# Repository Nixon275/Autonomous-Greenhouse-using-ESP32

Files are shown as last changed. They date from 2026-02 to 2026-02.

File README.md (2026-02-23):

# 🌱 Autonomous Greenhouse — ESP32 IoT System

> **Real-time monitoring and automatic regulation of microclimatic conditions in a plant growth enclosure, powered by ESP32 and the ESP RainMaker cloud platform.**

---

## What is this?

This project is a fully functional smart greenhouse system built around the **ESP32 microcontroller (ESP32-DevKitC V4)** and Espressif's **ESP-IDF** framework. It monitors and automatically controls the key environmental parameters that determine whether your plants thrive — all accessible from your phone, from anywhere in the world.

The system continuously reads five environmental parameters, sends the data to the cloud, and fires up actuators autonomously to keep conditions optimal — no human intervention required.

---

## 📸 Demo — Physical Build

<p align="center">
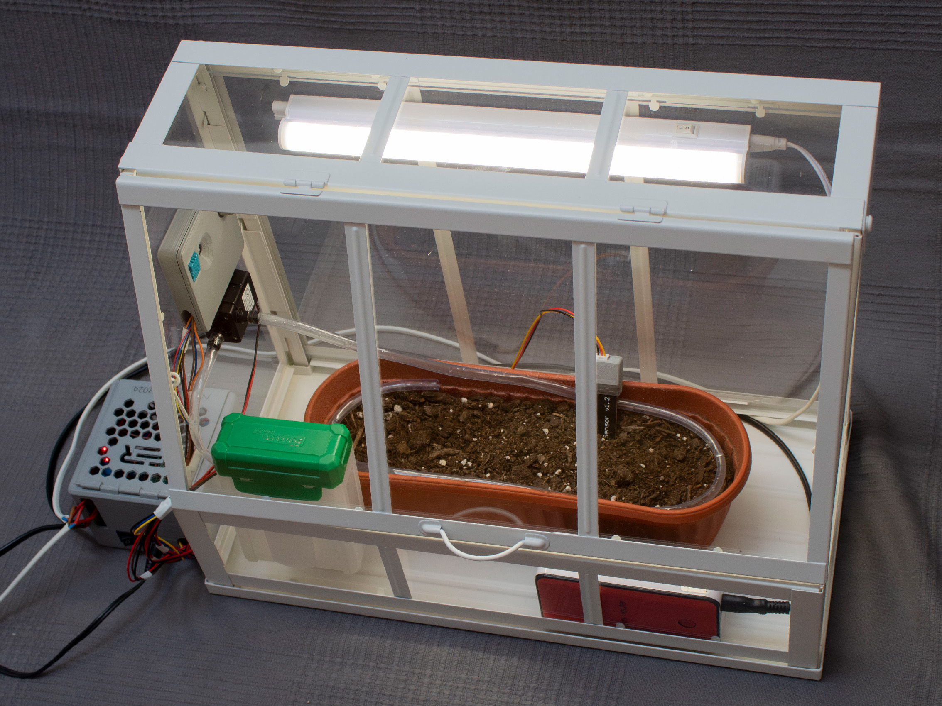
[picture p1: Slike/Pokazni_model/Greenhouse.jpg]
  
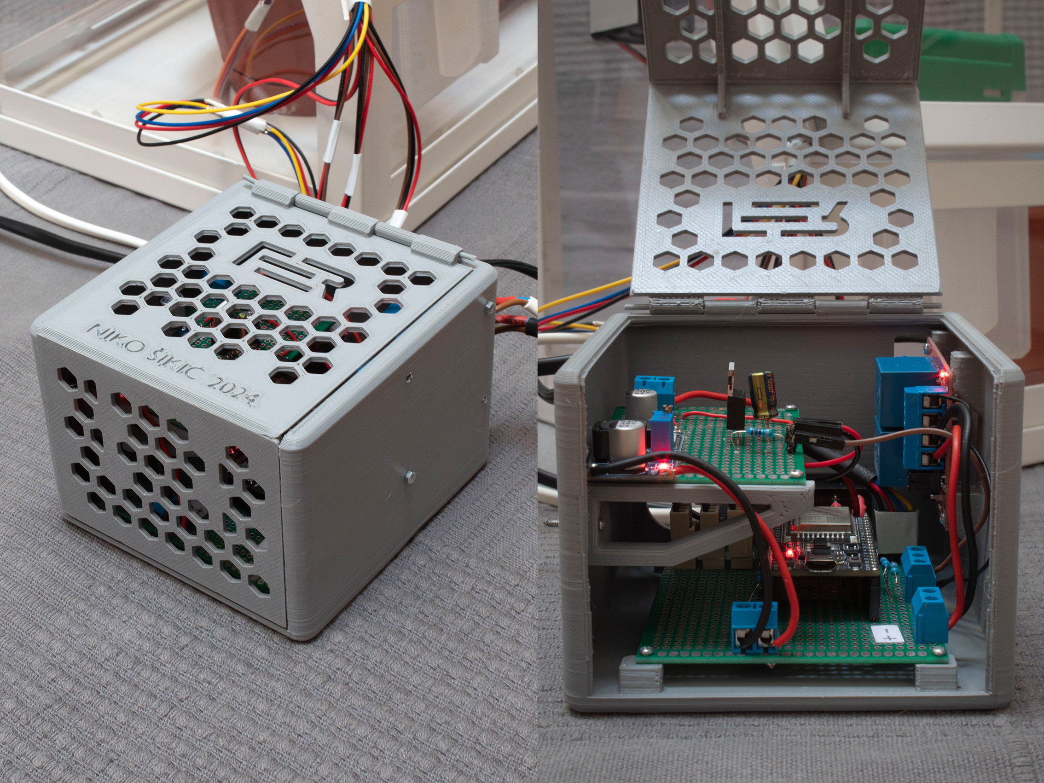
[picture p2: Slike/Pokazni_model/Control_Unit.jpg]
  
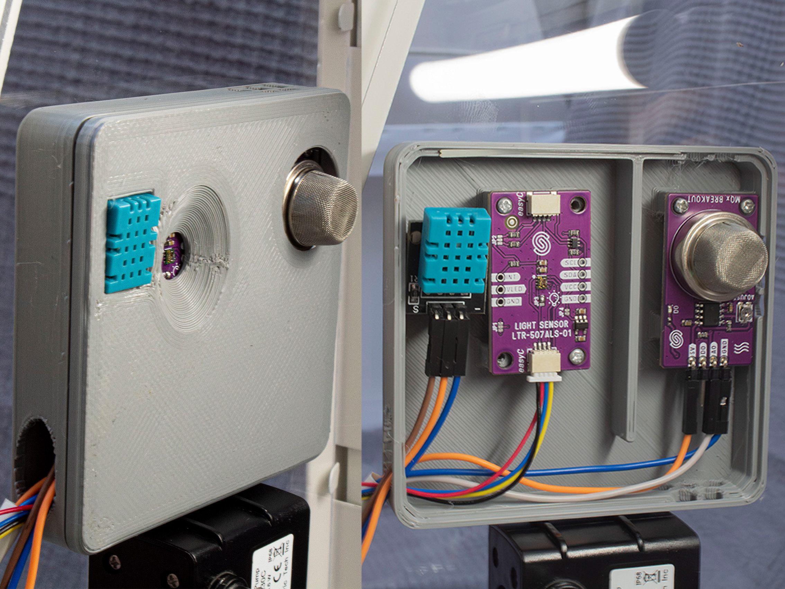
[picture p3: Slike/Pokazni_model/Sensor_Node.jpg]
  
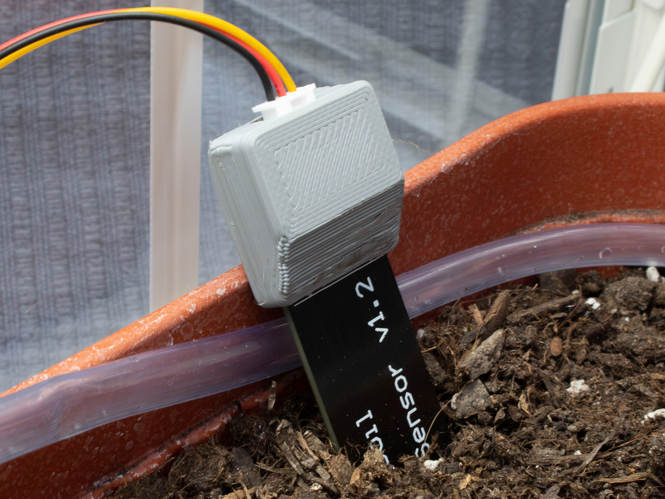
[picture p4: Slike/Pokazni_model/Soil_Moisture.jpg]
  
</p>

---

## 📐 System Architecture

<p align="center">
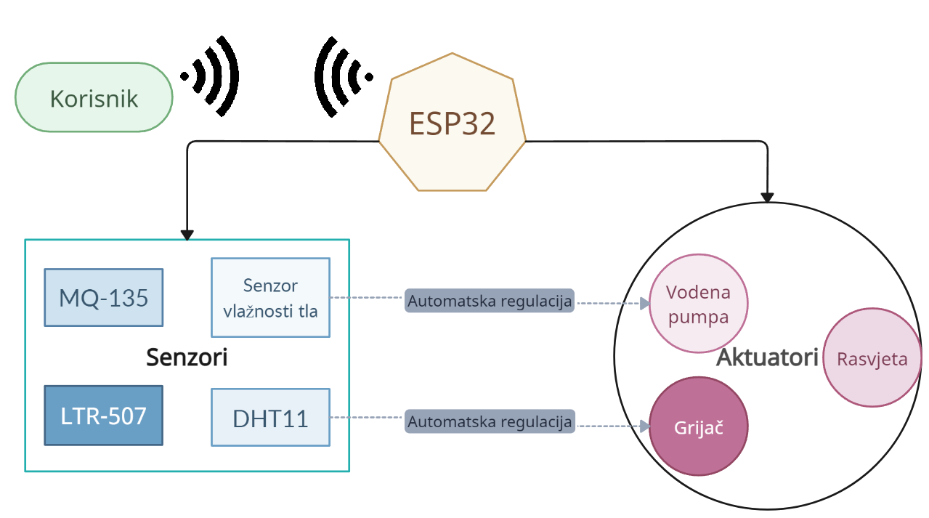
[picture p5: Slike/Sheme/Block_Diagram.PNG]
  
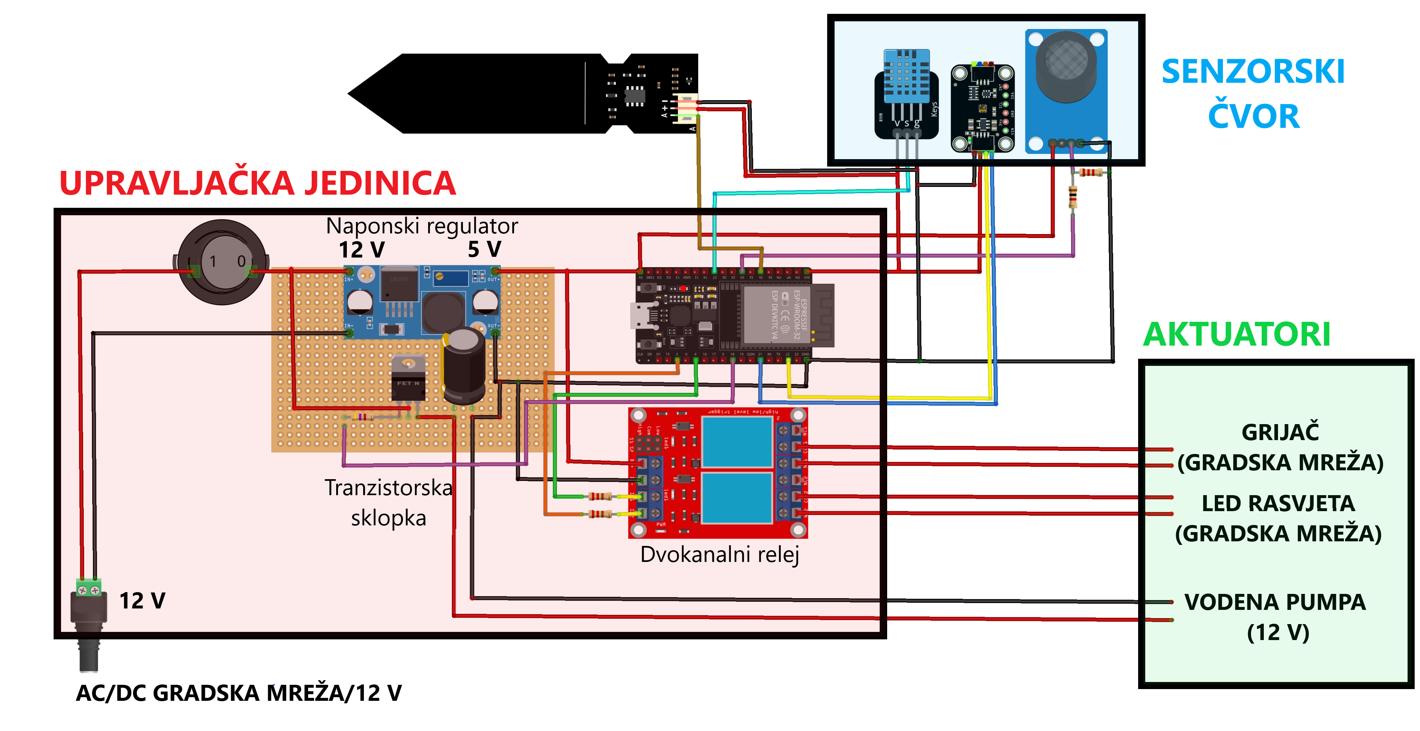
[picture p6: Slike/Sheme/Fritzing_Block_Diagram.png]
  
</p>

---

## ⚙️ What it monitors & controls

| Parameter | Sensor | Actuator |
|---|---|---|
| 🌡️ Air temperature | DHT11 | Electric heater |
| 💧 Air humidity | DHT11 | — |
| 🌿 CO₂ concentration | MQ-135 | — |
| 🪴 Soil moisture | Capacitive sensor v1.2 | Water pump |
| 💡 Light intensity | LTR-507-ALS-01 | LED grow light |

---

## 📱 Remote Access via ESP RainMaker

The system connects over **Wi-Fi** and streams sensor data to the **ESP RainMaker cloud**. Through the mobile app you can:

- View live and historical sensor readings (plotted over time)
- Set target temperature and soil moisture thresholds
- Manually toggle the LED grow light
- Schedule actuators based on time of day
- Get notified of parameter changes

---

## 🎬 Demo Video

> 📁 **[Watch the demo here →](https://drive.google.com/file/d/1RN_uDvcak08naD7JZQC7uZy4IQwOXqrC/view?usp=sharing)**

---

## 📄 Full Documentation

The complete written thesis (hardware design, sensor calibration, firmware architecture, and test results) is available in the repository:

📘 **[`Tekst/Sikic_Niko_Zavrsni_projekt.pdf`](Tekst/Sikic_Niko_Zavrsni_projekt.pdf)**

---

## 🛠️ Tech Stack

- **Microcontroller:** ESP32-DevKitC V4 (ESP32-WROOM-32E)
- **Framework:** ESP-IDF (C)
- **Cloud platform:** ESP RainMaker (MQTT over TLS)
- **Protocols:** 1-Wire (DHT11), I²C (LTR-507), ADC (MQ-135, soil sensor)
- **Control logic:** On/Off (bang-bang) regulation with FreeRTOS timers
- **Enclosures:** Custom-designed in Blender, 3D printed

---

## 📁 Firmware Structure

```
main/
├── app_main.c
├── app_driver.c
├── DHT11.c / .h
├── LTR-507.c / .h
├── MQ-135.c / .h
├── soil_moisture.c / .h
└── device.c / .h
```

---

*Bachelor's thesis — Faculty of Electrical Engineering and Computing (FER), University of Zagreb, 2024.*  
*Author: Niko Šikić | Mentor: Prof. dr. sc. Hrvoje Džapo*

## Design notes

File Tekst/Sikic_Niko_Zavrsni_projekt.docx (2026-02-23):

SVEUČILIŠTE U ZAGREBU

FAKULTET ELEKTROTEHNIKE I RAČUNARSTVA

Sustav za automatsko upravljanje mikroklimatskim uvjetima zatvorenog prostora za uzgoj biljaka

Niko Šikić

Zagreb, srpanj 2024.

Student: Niko Šikić

Naslov teme:

Sustav za automatsko upravljanje mikroklimatskim uvjetima zatvorenog prostora za uzgoj biljaka

Naslov teme (engleski):

A system for automatic control of the microclimatic conditions in rooms for growing plants

Studij:

Elektrotehnika i informacijska tehnologija

Mentor:

Prof. dr. sc. Hrvoje Džapo

Kratki opis:

Upoznati se s ključnim parametrima okolišnih uvjeta u zatvorenim prostorima za uzgoj biljaka (npr. plastenici, urbani vrtovi). Odabrati odgovarajuće senzore za praćenje okolišnih uvjeta (temperatura, vlaga, vlažnost tla, osvjetljenje, koncentracija plinova itd.). Upoznati se s aktuatorima za kontrolu parametara okolišnih uvjeta u zatvorenim prostorima za uzgoj biljaka (grijači, ventilatori, lampe i sl.). Upoznati se s arhitekturom mikrokontrolera ESP32 i programskim razvojnim okvirom ESP-IDF. Izraditi pokazni sustav temeljen na mikrokontroleru ESP32 te odabranim senzorima i aktuatorima koji će omogućiti nadzor i kontrolu parametara mikroklime u zatvorenom prostoru za uzgoj biljaka. Omogućiti povezivost sustava putem WiFi mreže, vezu prema udaljenom serveru, prikupljanje i pohranu podataka na server, prikaz trenutnog stanja mikroklime i kontrolu okolišnih parametara. Razviti korisničko sučelje za upravljanje sustavom i vizualizaciju podataka. Ispitati funkcionalnost rješenja na pokaznom sustavu.

Zahvaljujem profesoru Džapi i asistentici Salamun na pomoći pri izradi ovog rada te Poljoprivrednom institutu u Osijeku na obilasku komora rasta

Sadržaj

# 1. Uvod

Suvremeni uzgoj biljaka u zatvorenim prostorima podrazumijeva osiguravanje optimalnih mikroklimatskih uvjeta za njihov rast. U tu svrhu nastaju moderni staklenici s razvijenim sustavima za praćenje tih parametara. Ti sustavi nerijetko implementiraju izrazito učinkovite mehanizme automatske regulacije i time smanjuju ljudsku uključenost i poljoprivredne napore. To je izrazito važno za moderno društvo, koje podrazumijeva brzu i učinkovitu proizvodnju za prehrambene i istraživačke svrhe.

Danas dizajn takvih sustava postaje sve jednostavniji i pristupačniji. Staklenički se uzgoj sve češće uključuje u mrežu međusobno povezanih uređaja s ciljem pohrane i dijeljenja (senzorskih) podataka obuhvaćenu pojmom interneta stvari (engl. Internet of things – IoT). Zbog toga senzori, aktuatori i digitalni sustavi kojima se povezuju postaju dostupniji i jednostavniji za korištenje.

Glavni je cilj ovog rada ilustrirati primjenjivost rješenja interneta stvari u stakleničkom uzgoju. Ta će se primjenjivost demonstrirati izradom pokaznog modela staklenika, u kojem će se pratiti i regulirati mikroklimatski parametri te pohranjivati mjerni rezultati, koji će biti dostupni korisniku putem bežične mreže. Model će se temeljiti na mikrokontroleru ESP32 i platformi ESP RainMaker.

U drugom poglavlju predstavit će se moderni staklenički sustavi i objasniti važnost njihova razvoja. Također će se navesti najvažniji mikroklimatski parametri te senzori i aktuatori koji se najčešće koriste za njihovu regulaciju. Na kraju poglavlja predložit će se rješenje za izradu pokaznog modela za regulaciju tih parametara, čiji će dijelovi biti detaljnije opisani u poglavljima koja slijede. U trećem poglavlju opisan je mikrokontroler ESP32 i njegova bitna obilježja. Glavna obilježja korištenih senzora i pripadajući komunikacijski protokoli objašnjeni su u četvrtom poglavlju. Peto poglavlje posvećeno je odabranim aktuatorima i metodama njihova automatskog upravljanja. U šestom poglavlju predstavljena je platforma ESP RainMaker i programska potpora u jeziku C potrebna za rad pokaznog modela. Pokazni model sklopovski je i programski opisan u sedmom poglavlju.

# 2. Praćenje i regulacija uvjeta u stakleniku

## 2.1. Moderni staklenički uzgoj

Moderni su staklenici izrazito učinkoviti sustavi za uzgoj biljnih vrsta radi dobivanja poljoprivrednih proizvoda ili u istraživačke svrhe. Staklenički je uzgoj danas raširen u području botanike, vrtlarstva i prilagođen za komercijalnu proizvodnju. Načelo takvog uzgoja temelji se na održavanju stalnih mikroklimatskih uvjeta unutar staklenika neovisno o vanjskim klimatskim čimbenicima. Transparentni materijal staklenika (najčešće staklo ili plastika) omogućava prodor i zadržavanje vidljivog sunčevog zračenja, ali i cirkulaciju toplinske energije koju biljke zrače u infracrvenom spektru [1]. Na taj način moguć je uzgoj jestivih, ukrasnih, ljekovitih i dr. biljaka u bilo kojem klimatskom području. Staklenici se od drugih metoda uzgoja (pokrov poljoprivrednih redova, niski i visoki tuneli, mreže za zasjenjivanje i dr.) ističu po naprednijoj tehnološkoj izvedbi [2] i ubrzanom razvoju. Većina tehnoloških napora usmjerena je upravo prema praćenju mikroklimatskih uvjeta u stakleniku. Kontinuiranim mjerenjem okolišnih parametara dobiva se jasna slika o njihovu utjecaju na biljke, što služi kao smjernica pri optimalnom uzgoju. Poljoprivrednik ili botaničar prilagođava uvjete u stakleniku sukladno mjernim rezultatima. Takvo se reguliranje smatra ručnim (manualnim) i izrazito je izazovno i vremenski zahtjevno. Zato se razvijaju sustavi s autonomnom regulacijom, koji automatski pokreću aktuatore ovisno o senzorskim mjerenjima [3]. Tako se smanjuje ljudska uključenost i povećava produktivnost.

Daljnji napredak u uzgoju biljaka usmjeren je prema povezivanju hortikulturnih pametnih sustava u svrhu analize i vizualizacije mikroklimatskih parametara [1]. Dizajn takvih sustava postaje sve jednostavniji uspostavom bežičnih mreža međusobno povezanih uređaja koji dijele podatke i komuniciraju preko oblaka (engl. cloud). Takvi su sustavi obuhvaćeni pojmom interneta stvari (engl. Internet of things - IoT), koji predstavlja jednostavno i povoljno rješenje za obradu senzorskih podataka u stvarnom vremenu. Takva rješenja postaju sve dostupnija i cjenovno prihvatljivija; već se s komercijalnim senzorima i aktuatorima upravljanim jeftinim mikrokontrolerima mogu postići zadovoljavajući rezultati praćenja i regulacije mikroklimatskih uvjeta u stakleniku, što će se nastojati prikazati ovim radom.

Pristupačnost novih tehnologija i njihova upotreba u hortikulturi izrazito su važni za rješavanje globalnih problema poput gladi i siromaštva u sklopu održivog razvoja. Moderni hidroponski i aeroponski sustavi, poput onog prikazanog slikom (Slika 2.1), omogućuju visoku iskoristivost vode i zemljišta pri uzgoju hrane [4], a opremljeni su ugradbenim sustavima kojim se osiguravaju najbolji uvjeti za rast biljnih vrsta. Nadalje, posebne komore za uzgoj biljaka u kontroliranim uvjetima poput modularnih uređaja Fitotron prikazanih na slici (Slika 2.2) koriste se u farmaceutskoj industriji i u istraživačke svrhe.

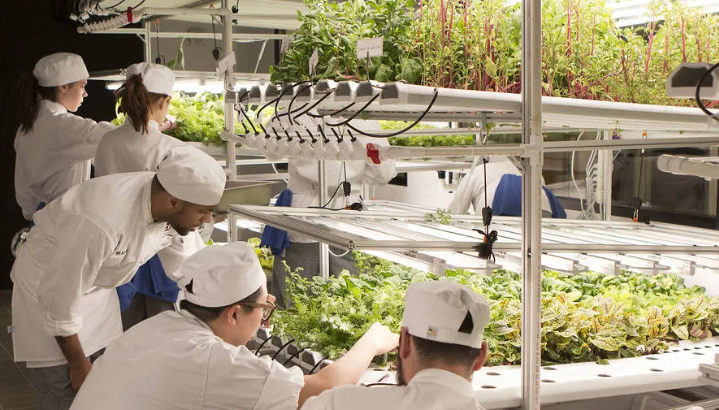
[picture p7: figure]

Slika 2.1 Hidroponski vrt njujorškog ICE-ja [5].

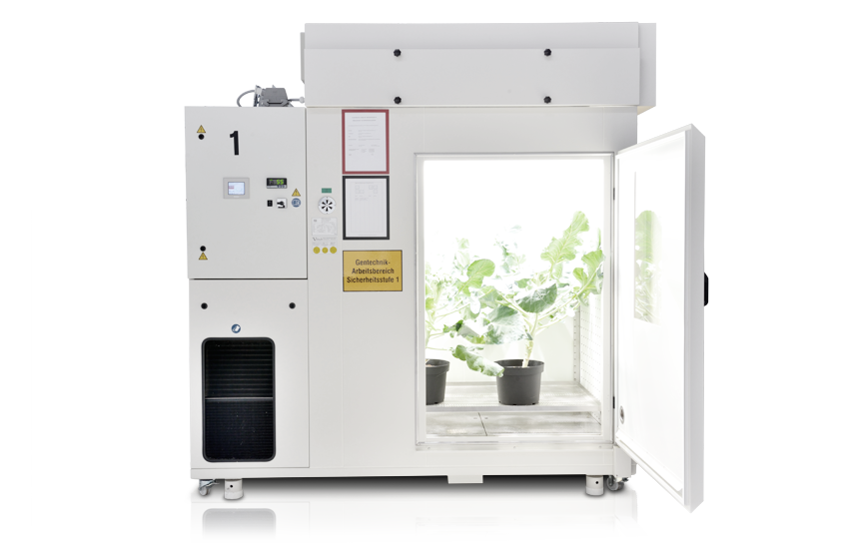
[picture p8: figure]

Slika 2.2 Komora rasta Fitotron tvrtke Weiss Technik [6].

## 2.2. Mikroklimatski parametri

Za izradu pokaznog modela razmatrani su sljedeći mikroklimatski parametri:

- temperatura zraka,
- vlažnost zraka,
- koncentracija ugljikova dioksida u zraku,
- vlažnost tla,
- intenzitet svjetlosti.

Oni su odabrani zbog njihove važnosti za uzgoj biljaka i dostupnosti senzora za praćenje mjernih rezultata. U nastavku slijedi kratak opis pojedinih parametara te najčešće upotrebljavani senzori i aktuatori za njihovo upravljanje.

### 2.2.1. Temperatura zraka

Osnovno načelo stakleničkog uzgoja temelji se na zadržavanju toplinske energije unutar zatvorenog prostora, a temperatura predstavlja fizikalnu veličinu kojom se ta toplina kvantificira. Temperatura unutar staklenika ne mora biti i najčešće nije jednoliko raspoređena. Ovisno o veličini, pojedini dijelovi staklenika mogu biti i do par stupnjeva topliji od drugih, pa je senzore potrebno postaviti na više mjesta [7].

Najčešće korišteni senzori jesu termoparovi, termistori i nešto skuplji otpornički temperaturni detektori (engl. Resistance Temperature Detector – RTD). Za većinu jednostavnih primjena, pa tako i za potrebe ovog rada, koriste se jeftini i manje pouzdani integrirani sklopovi za mjerenje temperature spremni za izravno spajanje na mikrokontroler [8].

Aktuatori za regulaciju temperature najčešće su realizirani toplinskim pumpama, električnim, plinskim i posebno održivim solarnim grijačima zraka. Koriste se i ventilacijski uređaji, kojima se toplina izmjenjuje s okolinom strujanjem zraka.

### 2.2.2. Vlažnost zraka

Vlažnost zraka predstavlja količinu vodene pare u zraku nastale u procesima isparavanja u tlu, transpiracijom biljaka, izmjenom vlage s okolinom zbog ventilacije i dr. Najčešće se izražava relativno u postotku i fizikalno je vezana uz temperaturu zraka. Zato se na tržištu često pojavljuju senzorski moduli kojima se mjere oba parametra [7].

Senzori se dijele u tri velike skupine: kapacitivni (engl. Capacitive Humidity Sensor – CHS), otpornički (engl. Resistive Humidity Sensor – RHS) i termički (engl. Thermal Conductivity Humidity Sensor – TCHS). Za zahtjeve brzog odziva i visoke preciznosti koriste se kapacitivni, a kod zahtjevnijih klimatskih uvjeta (visoka temperatura, otrovne pare) primjenjiviji su otpornički i termički senzori [8].

Kao i kod temperaturne regulacije, ventilatori su česti aktuatori. Osim njih, koriste se odvlaživači i posebni ovlaživači, koji osim povećavanja vlažnosti snižavaju i temperaturu zraka.

### 2.2.3. Koncentracija CO2 u zraku

Ugljikov je dioksid uz atmosferski kisik najvažniji plin za život biljaka. Biljke ga koriste za dobivanje energije u fotokemijskom procesu fotosinteze, pa je praćenje njegove koncentracije (najčešće relativno kao ppm, dio na 10⁶ dijelova) izrazito važno u hortikulturi. U zatvorenom prostoru staklenika drastično se povećava koncentracija CO2 (400 – 1000 ppm) u odnosu na atmosferu (oko 400 ppm) [7], a regulacija se provodi ventilacijom.

Senzori su podijeljeni u tri skupine: elektrokemijski, optički (infracrveni, NDIR) i metal-oksidni [8], kojima će se dati detaljniji opis u narednim poglavljima.

### 2.2.4. Vlažnost tla

Dostatna količina vode i mineralnih tvari u tlu ključna je za rast i razvoj biljaka, no prevelika količina može voditi do truljenja i smrti. Apsolutnu je vlažnost tla izrazito teško odrediti jer ovisi o brojnim faktorima poput gustoće i dielektričnosti tla, ali i svojstvima dodane vode i njezina utjecaja na tlo. Zato se vlažnost pojednostavljeno iskazuje gravimetrijski (maseni udio vode u tlu) ili volumetrijski (volumni udio vode u tlu). Kako se volumetrijsko mjerenje češće koristi, ono je odabrano za potrebe rada.

Praćenje se najčešće provodi mjerenjem napetosti vode tenziometrom i granularnim matričnim senzorom (engl. Granular Matrix Sensor – GMS) ili izravnog sastava vode u tlu reflektometrom vremenske domene (engl. Time Domain Reflectometry – TDR) i kapacitivnim senzorima [8]. Jeftini senzori spremni za spajanje na mikrokontroler najčešće su otpornički i kapacitivni, pa će se oni detaljnije razmatrati u narednim poglavljima.

Sustavi navodnjavanja u staklenicima postaju sve napredniji, a posebno se ističe automatska irigacijska regulacija [7], koja u kombinaciji s preciznim senzorima održava stalnu vlažnost tla štedeći vodu.

### 2.2.5. Intenzitet svjetlosti

Sunčevo zračenje biljkama omogućuje svjetlosnu energiju potrebnu za fotosintezu te toplinsku energiju za održavanje životnih uvjeta. Količina potrebne svjetlosti ovisi o biljnoj vrsti, a karakteristike svjetlosti o izvoru i strukturnim značajkama staklenika. Intenzitet vidljive svjetlosti obično se izražava u lumenima po četvornom metru (mjerna jedinica lux), a u hortikulturi češća je jedinica PPFD (gustoća fotosintetski aktivnog zračenja u μmol/m²/s), koja u obzir uzima svjetlosni spektar relevantan za biljni uzgoj (valne duljine 400 – 700 nm) [7].

Senzori za mjerenje vidljive svjetlosti najčešće su fotometrijski i fotootpornički, a u nešto skupljoj kategoriji ističu se piranometri za mjerenje ukupnog Sunčevog zračenja te kvantni svjetlosni senzori, kojima se najčešće mjeri PPFD [8].

Najčešći je aktuator LED rasvjeta za rast biljaka zbog niske potrošnje i robusnosti. Razvojem te tehnologije omogućeno je zračenje svjetlosti određene valne duljine prilagođene uzgajanoj biljnoj vrsti [7]. Njihov se rad automatski regulira ovisno o dnevnom ciklusu i životnom stadiju biljke.

## 2.3. Ciljevi rada i opis rješenja

Glavni je cilj rada ilustrirati primjenu IoT rješenja u stakleničkom uzgoju izradom pametnog sustava za praćenje i regulaciju mikroklimatskih uvjeta unutar pokaznog modela. Nakon evaluiranja senzora i aktuatora iz prethodnog poglavlja, uzimajući u obzir njihovu cijenu i dostupnost, odabrani su oni prikazani su tablici (Tablica 2.1).

Tablica 2.1 Prikaz odabranih senzora i aktuatora

Parametar | Senzor | Aktuator
Temperatura zraka | DHT11 | Električni grijač
Vlažnost zraka | | -
Koncentracija CO2 u zraku | MQ-135 | -
Vlažnost tla | Kapacitivni senzor | Vodena pumpa
Intenzitet svjetlosti | LTR-507ALS-01 | LED rasvjeta

Pokazni će model biti staklenik manjih dimenzija namijenjen za unutarnji ili vanjski prostor. Temeljit će se na mikrokontroleru ESP32 tvrtke Espressif, koji će obrađivati mjerne podatke senzorskog čvora i pogoniti aktuatorske elemente. Sustav će biti povezan na Wi-Fi mrežu, preko koje će se slati i pohranjivati mjerni podatci. Korisnik će moći tim podatcima pristupiti mobilnim uređajem spojenim na bilo koju mrežu te podesiti parametre regulacije i iscrtati rezultate. Blokovska shema sustava prikazana je slikom (Slika 2.3), a u narednim poglavljima pojašnjena je uloga svakog dijela sheme.


Slika 2.3 Blokovska shema pokaznog modela.

# 3. Ugradbeno računalo temeljeno na ESP32 mikrokontroleru

ESP32 jeftin je i moćan mikrokontroler koji proizvodi tvrtka Espressif Systems Company (Šangaj, Kina). Glavne su mu karakteristike brzi jednojezgreni ili dvojezgreni procesor, integrirane Wi-Fi i Bluetooth funkcionalnosti, velik broj izvoda GPIO opće namjene te rad prilagođen niskoj potrošnji. Mikrokontroler koristi snažni 32-bitni mikroprocesor Xtensa LX6, koji omogućava višezadaćnost i izvršavanje složenih zadataka. Također podržava brojne bežične protokole poput BLE (Bluetooth Low Energy), 802.11 b/g/n/e/I, WLAN MAC i Wi-Fi Direct. Protokolom Peer-to-Peer (ESP-NOW) omogućuje povezivanje više mikrokontrolera i neposrednu bežičnu razmjenu podataka. GPIO izvodi koriste se za pristup velikom broju vanjskih uređaja i komunikacijskih protokola. Među njima se ističu pretvornici ADC i DAC te sučelja I2C, SPI, UART i PWM [9]. Espressif također nudi niz razvojnih okvira kojim korisnicima olakšava razvoj IoT rješenja među kojima su: ESP RainMaker (upravljanje uređajima preko oblaka), ESP-WHO (okruženje za raspoznavanje lica), ESP-ADF (za zvučne aplikacije), ESP-DASH (kreiranje nadzornih ploča) te protokoli ESP-MESH i ESP-TLS.

## 3.1. Razvojni programski okvir ESP-IDF

Uobičajeni način programiranja mikrokontrolera jest pomoću razvojnog okvira koji omogućava Espressif pod nazivom ESP-IDF (engl. Espressif Systems Internet of Things Development Framework). Razvojni okvir sadrži potrebne biblioteke i izvorni kod za mikrokontroler, kao i potrebne skripte za alatni lanac (engl. toolchain) za prevođenje koda [10]. Također omogućava korisniku grafički izbornik za konfiguraciju naredbom idf.py menuconfig u terminalu. Opcijama u izborniku mogu se promijeniti postavke povezivanja (Wi-Fi, Bluetooth i dr.), memorije (NVS, particije memorije flash i dr.), periferija (ADC, I2C, SPI i dr.), načina rada niske potrošnje i slično. Najčešći programski jezik za programiranje ESP32 jest C, pa je u njemu pisana većina biblioteka. Mikrokontroler se jednako lako može programirati u jeziku C++ korištenjem Arduino biblioteka, no u radu je razmatrano programiranje u C-u [11].

## 3.2. Razvojni sustav ESP32-DevkitC V4

Za izvedbu rada odabrana je razvojna pločica ESP32-DevKitC V4 zbog njezine dostupnosti, male veličine i niske cijene. Na njoj se nalazi modul ESP32-WROOM-32E. Na pločici se nalaze dvije tipke: za ponovno postavljanje (engl. reset) i prenošenje programskog koda na mikrokontroler (engl. boot), ulaz tipa micro USB i USB-UART konverter za komunikaciju mikrokontrolera s računalom te ukupno 38 izvoda, koji uključuju izvod s 5 V i reguliranih 3.3 V. Pločica se može baterijski napajati preko ta dva izvoda ili preko USB konektora. Dijelovi razvojne pločice prikazane su slikom (Slika 3.1), a najbitnija obilježja modula ESP32-WROOM-32E tablicom (Tablica 3.1).

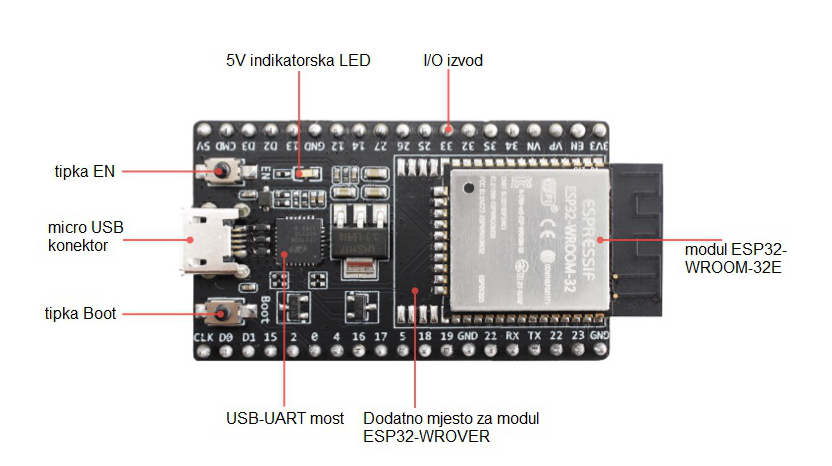
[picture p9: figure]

Slika 3.1 Glavni dijelovi ESP32-DevkitC V4 [12].

Tablica 3.1 Glavna obilježja modula ESP32-WROOM-32E [13].

Obilježje | Izvedba
Procesor i memorija | - Xtensa dvojezgreni 32-bitni procesor (do 240 Mhz) - 448 kB ROM - 520 kB SRAM - 16 kB SRAM RTC-a
Wi-Fi | - 802.11b/g/n - brzina (802.11n) do 150 Mbps - A-MPDU i A-MSDU agregacija - zaštitni interval 0.4 µs - središnja frekvencija 2412 - 2484 MHz
Bluetooth | - bluetooth V4.2 BR/EDR i BLE - Odašiljač klase 1/2/3 - AFH - CVSD i SBC
Periferije | - SD card, UART, SPI, SDIO, I2C, LED, (Motor) PWM, I2S, IR, brojač pulsa, GPIO, kapacitivni senzor dodira, ADC, DAC, TWAI®
Integrirane komponente | - kristalni oscilator 40 MHz - 4/16/8 MB SPI flash memorija
Antena | - na pločici
Uvjeti rada | - napajanje 3.0 – 3.6 V - radna temperatura -40 – 85 °C

## 3.3. Načini rada smanjene potrošnje

Iako će pokazni model biti napajan iz gradske mreže, zadatak svakog ugradbenog računalnog sustava jest smanjenje potrošnje. U tu svrhu ESP32 podržava dva načina rada niske potrošnje: light-sleep i deep-sleep. Ti načini rada niske potrošnje (engl. sleep) usporavaju ili u potpunosti zaustavljaju rad procesora, memorije i periferija. Uz to, mogu se podesiti uvjeti prelaska u pojedini način rada te hardverski i softverski pozivi koji vraćaju mikrokontroler u stanje uobičajene potrošnje (engl. wake-up calls).

U načinu rada light-sleep brzina je rada periferija, radne memorije i procesora ograničena te im je smanjena razina napajanja. S druge strane, u načinu rada deep-sleep iste su komponente potpuno isključene. Samo određene periferije ostaju uključene: RTC kontroler sa sporom i brzom memorijom te koprocesor iznimno niske potrošnje (engl. ultra low power – ULP). Kako oba načina isključuju bežične periferije, nisu primjenjivi za potrebe rada, u kojem je važno održavati stalnu Wi-Fi vezu.

Ako je potrebno održati stalnu bežičnu vezu uz nižu potrošnju, koristi se načini rada Wi-Fi i Bluetooth modem-sleep i automatski light-sleep. Definicije funkcija i konstanti uključene su u esp_wifi.h i esp_pm.h bibliotekama. Način rada modema pokreće se funkcijom esp_wifi_set_ps() koja prima jednu od tri konstante:

- PS_MODE_NONE; zadani način rada u kojem mikrokontroler radi bez optimizacije potrošnje,
- PS_MODE_MIN_MODEM; u tom se načinu rada mikrokontroler postavljen u način rada stanice (STA) budi na svaki DTIM (engl. Delivery Traffic Indication Message) zbog primanja malih paketa podataka (engl. beacon). Za korisnika važni podatci ne mogu biti izgubljeni jer se šalju nakon DTIM-a, ali trajanje DTIM-a određuje pristupna točka, pa ne dolazi do veće uštede ako je ono kratko.
- PS_MODE_MAX_MODEM; način rada modema najveće uštede. Mikrokontroler se budi svaki interval osluškivanja (engl. listen interval) kako bi primio beacon. Što je taj interval duži, to je veća ušteda energije, ali korisnički se podatci mogu izgubiti ako je mikrokontroler u neaktivnom stanju tijekom DTIM-a [14].

Interval osluškivanja postavlja se pozivom funkcije esp_wifi_set_config(), kojoj se predaje struktura wifi_config_t, u kojoj je interval definiran. Vrijeme u sekundama tijekom kojeg stanica (mikrokontroler) čeka beacon prije prekida veze postavlja se pozivom funkcije esp_wifi_set_inactive_time().

Pozivom funkcije esp_pm_configure() mogu se podesiti dodatne postavke uštede energije. Funkciji se predaje struktura esp_pm_config_t u kojoj se definira minimalna i maksimalna frekvencija rada, pa se na taj način frekvencija dinamički skalira (engl. Dynamic Frequency Scaling – DFS). U istoj se strukturi omogućuje automatski način rada light-sleep, u koji mikrokontroler ulazi na određeno vrijeme ako ne obavlja zahtjevne zadatke.

# 4. Senzori za praćenje okolišnih uvjeta

## 4.1. Senzor temperature i vlažnosti zraka DHT11

DHT11 digitalni je senzor temperature i vlažnosti zraka. Pokriva mjerno područje od 20 % do 90 % vlažnosti uz +/– 5 % preciznosti te od 0 °C do 50 °C uz +/– 2 °C preciznost pri mjerenju temperature. Senzor je tvornički kalibriran, a mjerne su vrijednosti obiju veličina izražene 8-bitnom cjelobrojnom vrijednošću. Senzor na pločici prikazan je slikom (Slika 4.1). Komunikacija s mikrokontrolerom odvija se serijski preko jedne podatkovne linije (izvoda GPIO) u obama smjerovima (engl. 1-Wire). Preko iste podatkovne linije obavlja se sinkronizacija i pravovremeno slanje podataka, a senzor postavlja vrijednosti na liniju samo kad mikrokontroler to zatraži. Prijenos podataka prikazan je slikom (Slika 4.2).

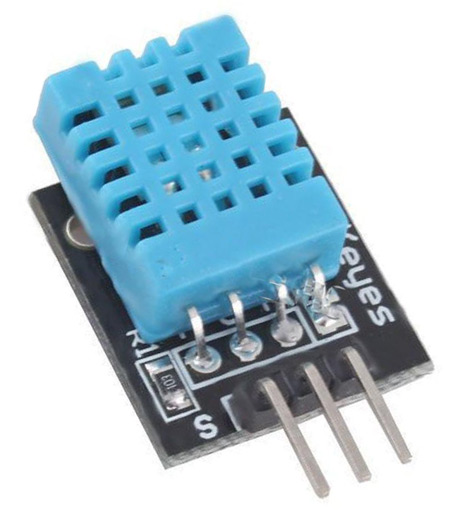
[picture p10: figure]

Slika 4.1 Pločica sa senzorom DHT11 [14].

Slika 4.2 Komunikacija mikrokontrolera (uređaj host) i senzora DHT11 (uređaj slave) [15].

Linija je prije početka komunikacije postavljena u stanje visoke naponske razine priteznim otpornicima, a senzor je u stanju niske potrošnje (izlazna struja oko 0,1 mA). Mikrokontroler pokreće komunikaciju slanjem start signala pritezanjem linije na nisku naponsku razinu minimalno 18 ms, nakon čega ju pušta i dopušta da se vrati na visoku razinu. To se postiže postavljanjem izvoda GPIO kao izlaznog, postavljanjem odgovarajuće razine i blokirajućom odgodom u mikrosekundama pozivom funkcije ets_delay_us(). Kad senzor primi početni signal, prelazi u aktivno stanje (izlazna struja od 0,5 do 2,5 mA) te nakon kraće odgode šalje potvrdni signal povlačenjem linije na nisku naponsku razinu 80 μs i otpuštanjem linije 80 μs. Odgoda se osigurava blokirajućim procesom trajanja minimalno 20 μs. Odgovor senzora potrebno je programski provjeriti, što se postiže pozivom funkcije wait_for_response(). Funkcija prima maksimalno vrijeme čekanja i logičku razinu odgovora koja ga predstavlja te u slučaju pravovremenog odgovora vraća ESP_OK, a u protivnom pogrešku oblika ESP_ERR_TIMEOUT. Programski je kod funkcije prikazan u odsječku koda 4.1.

esp_err_t wait_for_response (int time_us, int level)

{ int us_counter=0;

while (gpio_get_level(GPIO_pin) == level)

{

ets_delay_us(1);

us_counter++;

}

if (us_counter > time_us)

return output.status = ESP_ERR_TIMEOUT;

else

return ESP_OK;

}

Kôd 4.1 – Funkcija za čekanje određene logičke razine.

Nakon odgovora senzora kojim se osigurava sinkronizacija, senzor počinje slati mjerne podatke predstavljene u 40 bitova (5 bajtova), a prije svakog bita čeka se 50 μs. Binarna je nula predstavljena pritezanjem linije na masu u trajanju kraćem od 28 μs, a jedinica pritezanjem linije između 28 i 70 μs. Dekodiranje znamenki provodi se funkcijom sent_bit() koja vraća odgovarajuću znamenku po opisanom pravilu ili pogrešku ESP_ERR_INVALID_RESPONSE ako je linija bila u niskoj naponskoj razini više od 70 μs. 40 se dekodiranih bitova pohranjuje u 5 bajtova u polju DHT11_data[]. Prvi i treći bajt predstavljaju cjelobrojne rezultate temperature odnosno vlažnosti zraka, drugi i četvrti bit uvijek su 0 (korisni su za precizniji senzor DHT22 koji pohranjuje decimalne rezultate), a peti je bajt kontrolna suma za provjeru valjanosti čitanja [16]. Ako su mjerni podatci valjani, iznos kontrolne sume jednak je zbroju prethodna 4 bajta, u protivnom, program vraća pogrešku ESP_ERR_INVALID_SIZE. U svrhu pohrane mjernih rezultata i detekcije i obrade pogrešaka, inicijalizirana je statička struktura output tipa dht11_reading, u koju se pohranjuju temperatura, vlažnost zraka i status mjerenja. Na početku svakog mjerenja pretpostavljeni je status ESP_OK, a status se ažurira u slučaju bilo koje od spomenutih grešaka. Time se pozivom funkcije DHT11_read() dohvaćaju mjerni rezultati, ali i točan izvor pogreške ako je do nje došlo. Valja napomenuti da je opisani jednolinijski protokol vremenski vrlo osjetljiv te da lako može doći do problema kod sinkronizacije. Zbog toga se slanje senzorskih podataka smatra kritičnom sekcijom koja se ograđuje funkcijama portENTER_CRITICAL() i portEXIT_CRITICAL(). Njima se sprječavaju prekidi i pozivi drugih funkcija u istoj dretvi dok se odvija mjerenje.

## 4.2. Senzori spojeni na A/D pretvornik

### 4.2.1. Analogno-digitalna pretvorba na ESP mikrokontroleru

ESP32 koristi dva analogno-digitalna pretvornika sa sukcesivnom aproksimacijom za očitavanje analognih vrijednosti preko 18 mjernih kanala (ulaznih izvoda GPIO s alternativnom funkcijom). Napon na izvodu uspoređuje s referentnim te se digitalna vrijednost u zadanoj rezoluciji pridružuje očitanoj vrijednosti. Sučelje podržava dva načina rada: oneshot (pretvorba se odvija na zahtjev korisnika) i continuous (kontinuirano pohranjivanje rezultata za obradu podataka u stvarnom vremenu). Za potrebe rada razmatrao se samo način rada oneshot, čije su funkcije definirane u biblioteci esp_adc/adc_oneshot.h. Prije dohvata rezultata potrebno je odabrati postavke mjerenja pozivom funkcije adc_oneshot_config_channel(), kojoj se predaje referenca na odabrani SAR pretvornik (adc1_handle ili adc2_handle), odabrani mjerni kanal te konfiguracija rezolucije rezultata i atenuacije mjerenja. Uobičajen je raspon referentnog napona 1 – 1.2 V, a točan je iznos (ovisno o korištenoj pločici) pohranjen u eFuse vrijednosti te se automatski pridružuje ako je ta postavka omogućena u početnoj konfiguraciji (CONFIG_ADC_CALI_EFUSE_VREF_ENABLE=y). Atenuacijom se povećava mjerno područje ulaznog napona, a rasponi su prikazani u tablici (Tablica 4.1).

Tablica 4.1 Atenuacija i odgovarajuća mjerna područja ADC-a [17].

Atenuacija | Ulazni napon koji se može mjeriti
ADC_ATTEN_DB_0 | 100 mV – 950 mV
ADC_ATTEN_DB_2_5 | 100 mV – 1250 mV
ADC_ATTEN_DB_6 | 150 mV –1750 mV
ADC_ATTEN_DB_12 | 150 mV – 2450 mV

U radu je odabrana 12-bitna rezolucija i 12 dB atenuacija. Nakon postavljanja kanala očitanje vrijednosti počinje pozivom funkcije adc_oneshot_read(), koja digitalni rezultat u zadanoj rezoluciji pohranjuje u jedan od parametara. Kako se uz stvarne mjerne veličine analognih senzora (vlažnost tla, kvaliteta zraka) najčešće vežu izmjerene vrijednosti napona, potrebno je dobiveni digitalni rezultat pretvoriti u odgovarajući iznos napona. To se može postići jednostavnim omjerom, no ESP32 nudi posebno kalibracijsko sučelje koje korisniku omogućuje dohvat preciznijih naponskih očitanja. U biblioteci esp_adc/adc_cali.h definirana je funkcija adc_cali_create_scheme_line_fitting(), kojom se stvara shema za pridruživanje digitalnih vrijednosti. Funkciji se predaju podatci o korištenom kanalu, atenuaciji i rezoluciji u vidu konfiguracije adc_cali_line_fitting_config_t, a pozivom se funkcije ulaznom parametru funkcije predaje referenca na novonastalu shemu. Nadalje, ta se referenca predaje funkciji adc_cali_raw_to_voltage(), koja digitalnoj vrijednosti pridružuje odgovarajući iznos napona. Tako se dobivaju rezultati koji u obzir uzimaju točnu vrijednost referentnog napona iz memorije eFuse (ako ona nije dostupna, izbacuje se upozorenje i koristi predefinirana vrijednost) [17]. Razlike u dobivenim vrijednostima u ovisnosti o dvjema različitim vrijednostima referentnog napona prikazane su slikom (Slika 4.3). Konačno, vrijednosti se napona mogu pridružiti senzorskim mjernim rezultatima.

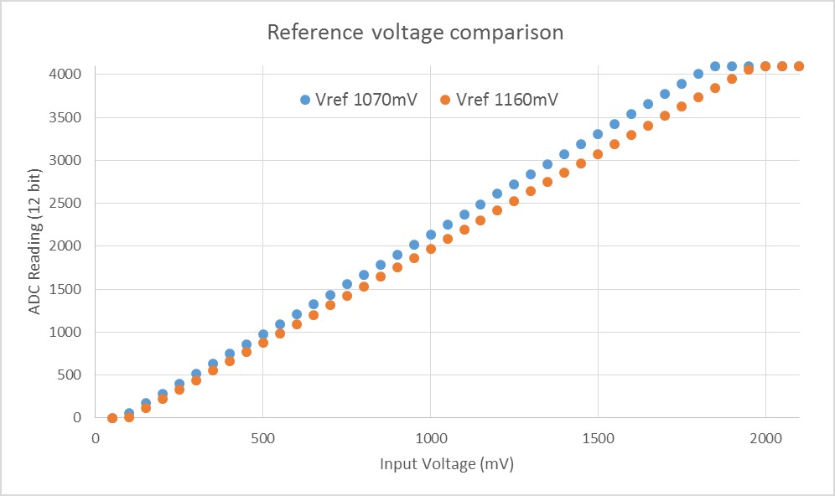
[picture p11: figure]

Slika 4.3 Prikaz odstupanja pri mjerenju s različitim referentnim naponima [17].

### 4.2.2. Senzor vlažnosti tla

Kapacitivni senzor vlažnosti tla (v1.2) široko je dostupan i jeftin analogni senzor. Napaja se preko pločice s 3,3 V te daje izlazni napon u efektivnom rasponu od 1,5 do 3 V (zbog toga je prikladna atenuacija ADC-a od 12 dB).

Ako se razmatraju samo jeftini komercijalno dostupni senzori, općenito postoje dva pristupa mjerenja vlažnosti tla. Prvi je direktno mjerenje otpora tla između dviju sondi senzora. Kroz tlo se pušta struja malog iznosa pomoću koje se računa otpor, koji se smanjuje što je tlo vlažnije, odnosno što je veća koncentracija vode u tlu. Najveći je problem tog pristupa izravan kontakt vodljivih sondi s tlom. Kako se preko njih zatvara strujni krug, dolazi do vidljive elektrolitske korozije sondi već nakon mjesec dana korištenja (Slika 4.4), pri čemu senzor djelomično ili potpuno gubi svoju funkcionalnost [19].

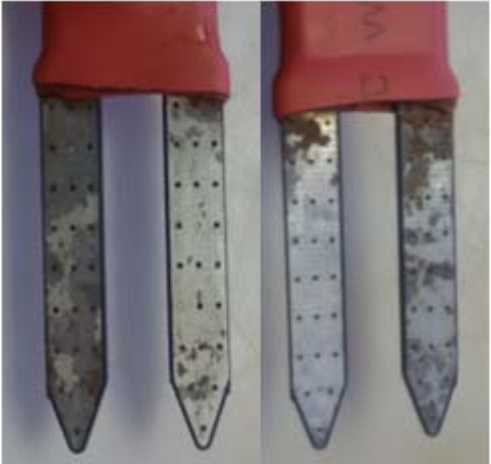
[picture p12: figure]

Slika 4.4 Korozija sondi otporničkog senzora [19].

S druge strane, senzor je zbog načina rada izrazito osjetljiv na promjenu koncentracije iona u tlu. Tako dolazi do većih odstupanja promjenom sastava tla uz istu vlažnost, primjerice, dodatkom gnojiva. Usto, otpor kao električka veličina znatno ovisi o temperaturi, pa i najmanje oscilacije utječu na rezultat. Zato takav pristup nije prihvatljiv za potrebe rada te se umjesto toga koristi kapacitivno mjerenje vlažnosti tla.

Senzori koji se temelje na kapacitivnoj metodi ustvari posredno mjere relativnu dielektričnu konstantu tla, koja se drastično povećava povećanjem koncentracije vode. Tipičan je iznos konstante za suho tlo 2 – 6, dok je za vodu blizu 80. Veličina preko koje se mjeri dielektričnost je rezonantna frekvencija kondenzatora određenog kapaciteta. Smanjivanjem dielektrične konstante dodatkom vode smanjuje se kapacitet, a iznos rezonantne frekvencije sklopa raste [20]. Frekvencija se zatim očitava brojačem LM555 i pretvara u analognu vrijednost; manju za veću vrijednost vlažnosti tla. U ovom pristupu nema izravnog kontakta vodljivih dijelova s tlom, pa je senzor otporan na koroziju. Također, temperaturna promjena kapaciteta u odnosu na otpor znatno je manja, pa je senzor prikladniji za stakleničke uvjete. Izgled senzora prikazan je slikom (Slika 4.5).

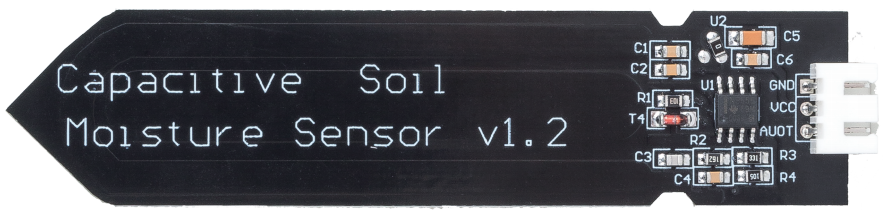
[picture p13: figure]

Slika 4.5 Kapacitivni senzor vlažnosti tla v1.2 [21].

Kalibracija senzora izvodi se pridruživanjem izmjerenih vrijednosti volumetrijske vlažnosti tla odgovarajućim iznosima napona. Provedeno je deset mjerenja, pri čemu se vlažnost tla (θv) računala preko mase mokrog (ms) i suhog (md) tla te gustoće vode (ρw) i nasipne gustoće tla (ρd,s) izrazom (1):

θ_v = ((m_s -m_d)/(m_d))(ρ_(d,s))/(ρ_w) (1)

Detaljniji je postupak mjerenja opisan u radu [20]. Izmjerene su vrijednosti potom unesene u konstante VOLTAGE_READINGS odnosno MOISTURE_READINGS u datoteci soil_moisture.h. Pretpostavljen je linearni odnos između inverza naponske razine i odgovarajuće vlažnosti tla te se u funkciji soil_moisture_init() metodom najmanjih kvadrata određuju koeficijenti aproksimiranog pravca. Mjerni su rezultati prikazani u tablici (Tablica 4.2), a aproksimacija pravcem slikom (Slika 4.6). Tom je metodom dobiven izraz s korijenom srednje kvadratne pogreške (RMSE) iznosa 0.032377 (odstupanje pri mjerenju vlažnosti ispod 5 %), koja je u prikladnom rasponu za uređaje slične primjene [20]. Taj se izraz koristi u funkciji read_soil_moisture(), čijim se pozivom dohvaća konačna vrijednost vlažnosti tla.

Tablica 4.2 Rezultati mjerenja vlažnosti tla u pokaznom modelu.

Volumetrijska vlažnost tla [%] | Izmjereni napon [V]
1,00 | 2,1
3,009 | 2,01
11,434 | 1,875
25,075 | 1,57
29,689 | 1,32
36,510 | 1,28
42,127 | 1,13
47,543 | 1,03
52,157 | 0,95
58,980 | 0,92

Slika 4.6 Aproksimirana krivulja kalibracije nacrtana alatom MATLAB.

### 4.2.3. Senzor plinova MQ-135

Senzori oznake MQ vrlo su dostupni i jeftini analogni senzori za raspoznavanje atmosferskih plinova. Senzori koriste metal-oksidni poluvodički materijal (najčešće SnO2), koji mijenja otpor u kontaktu s plinom. Kako se otpor mijenja i promjenom temperature, u senzorima se postavlja i grijaća žica, koja održava temperaturu senzora visokom i time smanjuje temperaturne oscilacije. Zbog toga je prije dohvata prvih točnih mjernih rezultata potrebno zagrijavati senzor određeno vrijeme koje propiše proizvođač [22]. Senzor oznake MQ-135 prikazan je na slici (Slika 4.7).

Slika 4.7 Pločica sa senzorom MQ-135 [27].

MQ-135 podešen je tako da mijenja otpor ovisno o koncentraciji amonijaka, parama alkohola, benzena, ugljikova dioksida, dima i drugih plinova. Kao osjetljivu tvar koristi SnO2, poluvodički materijal n-tipa, kojem otpor pada u doticaju sa spomenutim reducirajućim plinovima. Senzor se napaja preko 5 V te sadrži analogni i digitalni izlaz. Na digitalni se izlaz postavlja logička jedinica ovisno o naponu postavljenom potenciometrom te se neće daljnje razmatrati u radu. Analogni je izlazni signal u rasponu 0 – 5 V te se koristi pri izračunu otpora senzora (RS) koji ovisi o koncentraciji određenog plina u zraku. Taj otpor zajedno s teretnim otporom (RL) iznosa 10k zatvara izlazni strujni krug prikazan slikom (Slika 4.8). Otpor senzora računa se izrazom (1), pri čemu je VRL napon na otporniku RL odnosno mjereni analogni izlaz.

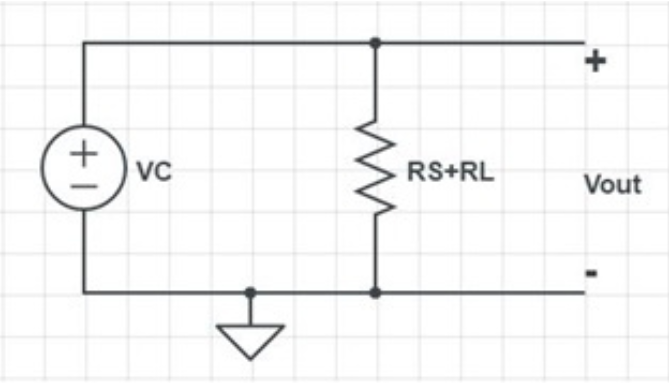
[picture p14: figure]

Slika 4.8 Pojednostavljena shema izlaznog strujnog kruga senzora MQ-135 [26] .

R_S = (V_C ∙ R_L)/(V_(R_L))-R_L (1)

Odgovarajuća koncentracija plinova pridružuje se danom otporu po shemi koju osigurava proizvođač. Senzor će se koristiti za mjerenje koncentracije ugljikova dioksida, pa se razmatra kalibracijska krivulja tog plina. Kako je shema pridruživanja dana u logaritamskoj skali, krivulja se prilagođava eksponencijalnoj funkciji oblika y=ax^b , gdje se aproksimiraju koeficijenti a i b pomoću točaka na shemi prikazanoj slikom (Slika 4.9). Tim postupkom [25] dobiven je izraz (2), pri čemu je R0 referentni otpor proizvođača izmjeren pri standardnim uvjetima i koncentracije 100 ppm amonijaka u zraku [22].

ppm = 116.6∙((R_S)/(R_0))^(-2.769) (2)

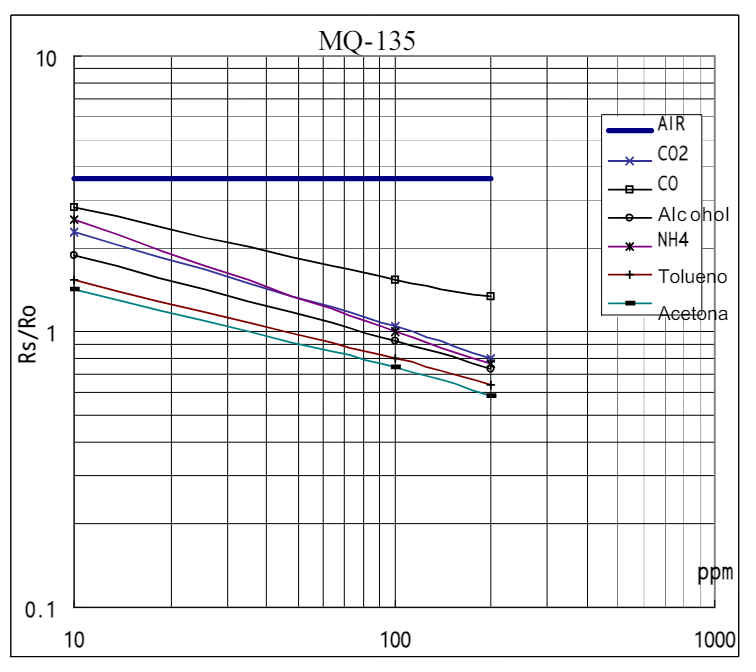
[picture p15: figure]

Slika 4.9 Osjetljivost senzora MQ-135 na različite atmosferske plinove [22].

Za potrebe rada R0 izračunat je iz izraza (1) iz izmjerenog otpora senzora RS pri poznatoj koncentraciji ugljikova dioksida. Kako se nije provodilo mjerenje koncentracije drugim kalibriranim uređajem, uzeta je atmosferska vrijednost od 425 ppm [24], a otpor R0 dobiven usrednjavanjem više izmjerenih vrijednosti izlaznog napona iznosi 122264 Ω. Dobivene su vrijednosti upisane kao konstante u datoteku MQ135.h. Funkcija MQ135_init() inicijalizira ADC, MQ135_read_voltage() vraća rezultat pretvorbe u voltima, a MQ135_read() računa konačnu vrijednost koncentracije ugljikova dioksida u zraku pomoću izraza (2).

Valja napomenuti da se opisanim postupkom ne mogu dobiti potpuno točni rezultati. Senzori oznake MQ ne razlikuju tipove detektiranih plinova. Promjena vrijednosti ppm ne znači nužno promjenu koncentracije ugljikova dioksida u zraku, nego bilo kojeg reducirajućeg plina koji mijenja otpor senzora. Osim toga, neprecizna aproksimacija referentnog otpora R0 također je znatan izvor pogreške. Zbog toga se senzor MQ-135 u radu može koristiti za grubo oslikavanje koncentracije ugljikova dioksida u stakleniku i kao sigurnosni mehanizam protiv požara ako se koncentracija poveća iznad dozvoljene granice. Za precizno mjerenje koncentracija plinova u zraku koriste se skupi i precizni digitalni senzori posebno prilagođeni karakteristikama određenog plina [23].

## 4.3. Senzori spojeni putem I2C sučelja

### 4.3.1. I2C komunikacijski protokol

Razvojem sve složenijih ugradbenih sustava pojavljuje se potreba za komunikacijom sa sve većim brojem perifernih uređaja. U isto se vrijeme teži sve manjim dimenzijama uređaja, a veći broj veza povećava fizičke dimenzije pločice. Dakle, potrebno je omogućiti spajanje što većeg broja vanjskih uređaja bez nagomilavanja električnih veza. U tu svrhu 1982. tvrtka Philips Semiconductor (danas NXP Semidonductors) razvija komunikacijski protokol I2C (engl. I-squared-C) [28]. Komunikacija između uređaja koji podržavaju taj protokol odvija se jednostavnom dvožičnom sabirnicom pri čemu se uređaji jedinstveno adresiraju. Prijenos podataka odvija se pri nižim brzinama (od 100 kHz do 5 MHz, najčešće 400 kHz), a maksimalan broj povezanih uređaja određen je širinom adresa (tipično 112 kod 7-bitnih adresa, znatno više kod 10-bitnih). Dvije dvosmjerne linije tipa open drain preko kojih se odvija komunikacija jesu SDA (serijska podatkovna linija), preko koje se šalju podatci, i SCL (serijska taktna linija), kojom je određen takt prijenosa. Uređaj koji inicira prijenos podataka naziva se master, a uređaji koje adresira smatraju se uređajima slave. Podatci koji se prenose sastoje se od adrese uređaja slave i kontrolnih bitova za početak, završetak, smjer i mehanizam potvrđivanja prijenosa [29] . Spajanje uređaja prikazano je slikom (Slika 4.10).

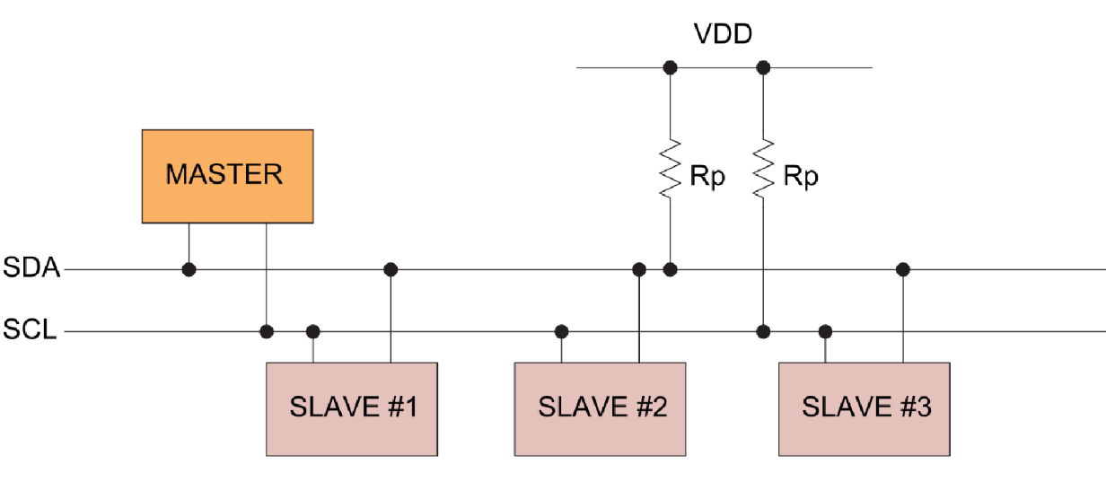
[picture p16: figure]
Figure 1: Generalized I2C Connection Diagram

Slika 4.10 Blokovska shema spajanja uređaja pri I2C komunikaciji Pogreška! Izvor reference nije pronađen. .

Prije početka prijenosa (engl. idle) obje su linije priteznim otpornicima postavljene u stanje logičke jedinice. Početak prijenosa inicira master spuštanjem SDA linije iz stanja “1” u stanje “0” dok je linija SCL u stanju “1”. Nakon start uvjeta master na liniju postavlja 7-bitnu adresu uređaja kojemu pristupa i bit kojim određuje hoće li čitati podatak s SDA linije ili će postaviti podatak na nju. Nakon što slave potvrdi da je ispravno adresiran slanjem signala ACK, podatci se mogu postaviti na liniju. Ako se radi o operaciji čitanja, slave postavlja 8-bitne podatke, a master prvo potvrđuje da ih je primio slanjem signala ACK te ih potom čita. U slučaju pisanja master postavlja podatke na podatkovnu liniju, a slave potvrđuje da ih je primio te ih potom čita. Podatci se mogu čitati odnosno pisati s linije sve dok master signalom NACK ne označi posljednji podatak i prekine prijenos slanjem stop uvjeta postavljanjem SDA linije u “1” dok je SCL u “1”.

### 4.3.2. I2C komunikacija na ESP32 mikrokontroleru

Mikrokontroler ESP32 posjeduje dva I2C kontrolera (engl. port), koji se mogu konfigurirati u načinu rada master ili slave. Način rada slave podrazumijeva drugi mikrokontroler koji preuzima ulogu uređaja master, pa se neće dalje razmatrati u ovom radu. Način rada master jednostavno se implementira API-jima definiranim u bioblioteci i2c_master.h. Prije prijenosa podataka potrebno je inicijalizirati uređaj master i dvolinijsku sabirnicu preko koje komunicira. Prvo se inicijalizira sabirnica pozivom funkcije i2c_new_master_bus kojoj se predaje konfiguracija i2c_master_bus_config_t i upravljač (engl. handle) i2c_master_bus_handle_t, koji predstavlja sabirnicu. U konfiguraciji postavlja se I2C port, broj izvoda GPIO za SDA i SCL, izvor takta (100 kHz za standardni način rada, 400 kHz za brzi način rada), period pogreške (ako pogreška u komunikaciji traje manje od zadanog perioda, moguće ju je filtrirati), pritezni otpornik linije i dr. Nakon poziva funkcije stvara se instanca konfigurirane sabirnice koja se predaje idućoj funkciji i2c_master_add_device(), kojom se inicijalizira master uređaj. Funkciji je također potrebno predati konfiguraciju i2c_device_config_t, kojom se definira adresa uređaja kojem uređaj master pristupa i njezina širina (7 ili iznimno 10 bita) te brzina takta SCL. Programski je kod za inicijalizaciju sučelja prikazan programskim odsječkom 4.2.

i2c_master_bus_config_t i2c_mst_config = {

.clk_source = I2C_CLK_SRC_DEFAULT,

.i2c_port = I2C_PORT,

.scl_io_num = I2C_MASTER_SCL_IO,

.sda_io_num = I2C_MASTER_SDA_IO,

.glitch_ignore_cnt = 7,

.flags.enable_internal_pullup = true,

};

i2c_master_bus_handle_t bus_handle;

ESP_ERROR_CHECK(i2c_new_master_bus(&i2c_mst_config, &bus_handle));

Kôd 4.2 – Inicijalizacija sučelja I2C.

Konačno, nastaje konfigurirani uređaj master predstavljen s i2c_master_dev_handle_t, kojim se započinje prijenos podataka. Funkcijom i2c_master_transmit() mikrokontroler piše podatke uređaju slave, pozivom i2c_master_receive() čita se iz njega, a pomoću i2c_transmit_and_receive() master prvo piše pa čita podatke s linije [18].

### 4.3.3. Senzor ambijentnog osvjetljenja i udaljenosti LTR-507

LTR-507ALS-01 optički je digitalni senzor ambijentnog osvjetljenja i udaljenosti. Senzor pretvara analogni intenzitet svjetlosti u digitalni signal koji se odašilje sučeljem I2C. Uređaj nudi spektralni odziv sličan onome kod ljudskog oka, radi u različitim uvjetima osvjetljenja te automatski odbacuje 50 i 60 Hz treperenje, koje bi narušilo mjerenje. Također se može koristiti i za procjenu udaljenosti s ugrađenim infracrvenim LED driverom, ali ta funkcionalnost nije implementirana u svrhe ovog rada. Mikrokontroler komunicira sa senzorom standardnim (100 kHz), brzim (400 kHz) i jako brzim (3,4 MHz) prijenosom I2C, pri čemu se senzor postavlja u stanje niske potrošnje (engl. standby/sleep mode) kad se na sabirnici ne odvija prijenos [31]. Prije prvog mjerenja potrebno je postaviti početne postavke senzora. To se, kao i pristupanje mjernim podatcima, obavlja upisom određenih konstanti u podatkovne registre senzora. Pločica sa senzorom prikazana je slikom (Slika 4.11), a primjer upisa vrijednosti u podatkovni registar shemom (Slika 4.12).

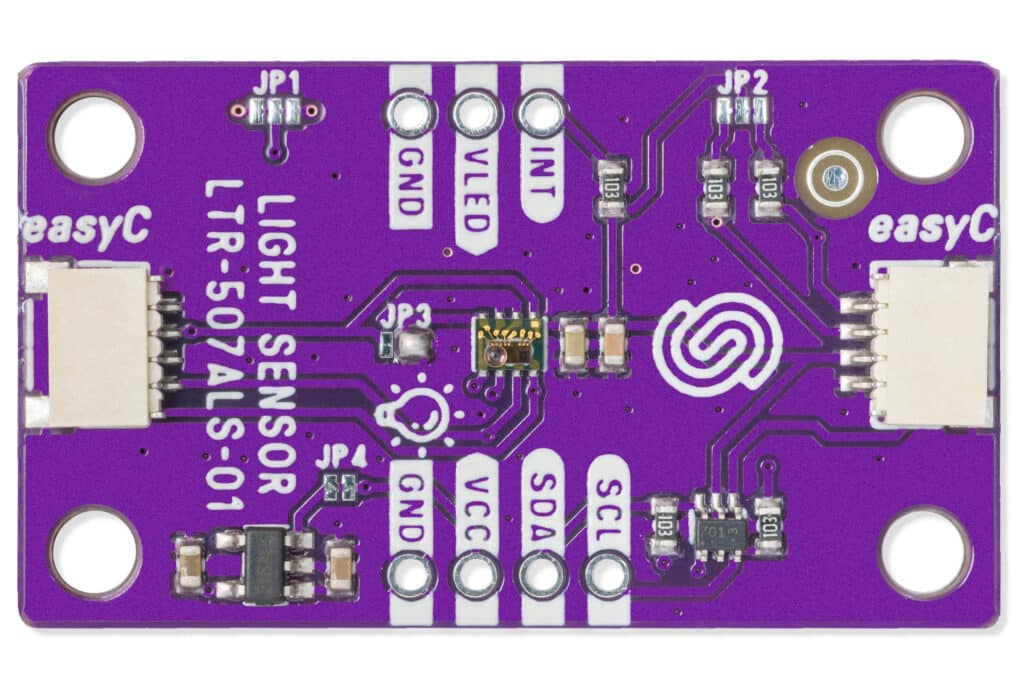
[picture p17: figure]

Slika 4.11 Pločica sa senzorom LTR-507-ALS-01 [32].

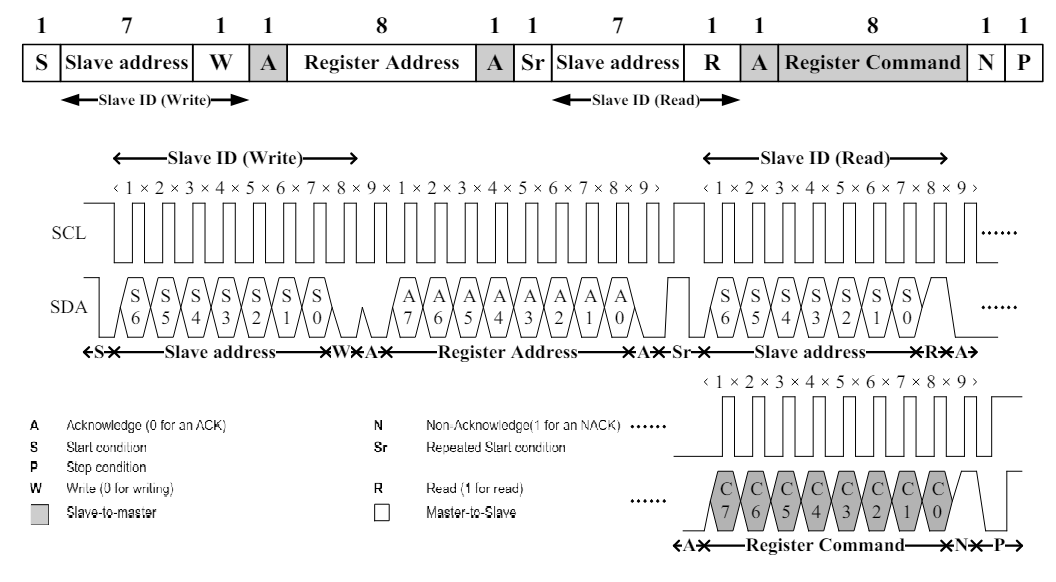
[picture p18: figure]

Slika 4.12 Pisanje u podatkovni registar senzora LTR-507-ALS-01 [31].

Prvo se inicijalizira sučelje I2C uređaja na prethodno opisan način; adresa senzora je 7-bitna iznosa 0x23. Registrima za inicijalizaciju pristupa se tako da se na liniju SDA prvo pošalje 8-bitna adresa registra, a potom se iščitava ili ažurira njegova vrijednost ovisno o tome radi li se o operaciji čitanja ili pisanja. Za čitanje vrijednosti registara najprikladnija je funkcija i2c_transmit_and_receive(), kojom se prvo upisuje adresa registra te se čita njegova vrijednost, a za pisanje u registar koristi se funkcija i2c_transmit(), pri čemu se odmah prenose dva podatka (prvo adresa pa nova vrijednost registra). Na taj način u funkciji ALS_Enable() senzor se iz neaktivnog (standby) stanja postavlja u aktivno, a zatim se namještaju drugi parametri: dinamički raspon mjerenja (setALSGain()), rezolucija analogno-digitalnog pretvornika (setALSBitWidth()) te brzina očitavanja (setALSMeasRate()). Konačno, 16-bitna cjelobrojna vrijednost intenziteta svjetlosti izražena u luxima dohvaća se pozivom funkcije LTR507_getLightIntensity(), pri čemu se prije pristupanja podatkovnom registru provjerava ispravnost rezultata čitanjem vrijednosti statusnog registra LTR507_ALS_PS_STATUS_REG.

# 5. Aktuatori za automatsku regulaciju uvjeta

Aktuatori u pokaznom modelu implementiraju ručnu i automatsku regulaciju. Kako osvjetljenje u stakleniku ovisi o biljnoj vrsti i dnevnom ciklusu, ono nije izravno povezano sa senzorskim mjerenjem u mjernoj jedinici lux. Zbog toga je za rasvjetu omogućena ručna regulacija, pri čemu se ona pali i gasi s obzirom na korisnikov unos. Iznimno, u korisničkoj će aplikaciji biti omogućeno automatsko upravljanje rasvjetom ovisno o vremenu tijekom dana. Na primjeru vodene pumpe (3,6 W) i električnog grijača (50 W) ilustrirat će se osnovni principi automatske regulacije.

## 5.1. Algoritmi automatske regulacije

Najpopularniji tip industrijskog automatskog upravljanja jest PID regulacija. Mjerna vrijednost senzora negativnom se povratnom vezom (Slika 5.1) oduzima od korisnički postavljene vrijednosti te se rezultat provlači kroz PID regulator. PID regulator zasniva se na proporcionalnom (P), integracijskom (I) i derivacijskom (D) djelovanju, kojima se podešavaju aktuatorski parametri. Takav se pristup koristi u 95 % industrijskih primjena, nudi mogućnosti automatskog podešavanja (engl. autotuning) i samopodešavanja (engl. selftuning) parametara [33]. Problem takva pristupa jest što zahtijeva kontinuiranu kontrolu nad aktuatorskim izlazom. Kako će se u pokaznom modelu grijačem i pumpom upravljati sklopkama (relejom i tranzistorskom sklopkom), dakle bez mogućnosti kontrole snage pumpanja i jačine grijanja, PID regulacija nije primjenjiva.

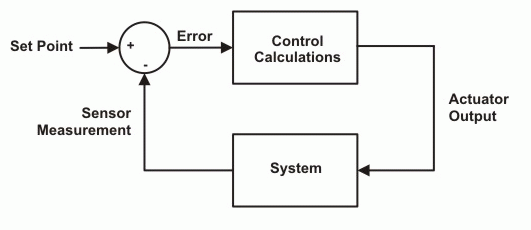
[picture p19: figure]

Slika 5.1 Osnovna ideja automatskog upravljanja s povratnom vezom [35].

Za sustave bez mogućnosti podešavanja primjenjiva je automatska regulacija tipa uključi-isključi (engl. on/off, bang-bang). Metoda se zasniva na postavljanju gornje i donje granice mjerenog parametra te se paljenjem ili gašenjem aktuatora veličina održava u željenom intervalu. Dakle, koristi se samo proporcionalno regulatorsko djelovanje, kojim se upravlja aktuatorima [34]. Osnovni je princip te metode prikazan slikom (Slika 5.2). Iako je ovaj tip regulatora manje precizan od prethodnog, izrazito je jednostavan za realizaciju i primjenjiv u mnogim situacijama.

Slika 5.2 Osnovni princip automatske regulacije tipa uključi-isključi [34].

## 5.2. Izvedba rješenja u sustavu za regulaciju uvjeta u stakleniku

Za pokazni je model korišten modificirani oblik regulacija tipa uključi-isključi bez postavljanja dviju granica. Iznad opisani način primjenjiv je za situacije u kojima se senzorsko mjerenje provodi gotovo kontinuirano. U pokaznom će se modelu mjerene veličine očitavati rjeđe zbog smanjenja potrošnje. Češća mjerenja nisu nužna jer ne dolazi do većih oscilacija promatranih parametara, a i time se osigurava dovoljno vremena za pripremu mjernih rezultata kod sporijih senzora.

Ilustracijski je princip regulacije izrazito jednostavan: pri svakom se senzorskom očitanju provjerava uvjet prema kojem se po potrebi uključuje odgovarajući aktuator na definirano vrijeme. Dakle, pumpa i grijač će se periodički paliti svakoga intervala očitavanja ako je vlažnost tla odnosno temperatura zraka manja od korisnički definirane vrijednosti. Trajanje navodnjavanja odnosno grijanja postavlja se eksperimentalno, ovisno o radu aktuatora.

Za periodička očitavanja i aktivaciju aktuatora koriste se brojači u sklopu operacijskog sustava za rad u stvarnom vremenu pod nazivom FreeRTOS (engl. Real Time Operating System – RTOS) integriranog u ESP32. Funkcije za brojače definirane su u biblioteci freertos/timers.h. Funkcijom xTimerCreate() stvara se brojač kojem se pridružuje ime, vrijednost do koje se broji u otkucajima (engl. tick), zastavica koja se postavlja na pdTrue ako je brojač periodičan, identifikator te funkcija koja se poziva kad brojač odbroji do zadane vrijednosti. Otkucaji se preračunavaju u milisekunde korištenjem konstante portTICK_PERIOD_MS. Na taj način inicijalizirani su brojači za senzore, vodenu pumpu i grijač, koji započinju brojenje pozivom funkcije xTimerStart(). U funkciji povratnog poziva senzora pozivaju se funkcije za mjerenje iz prethodnog poglavlja te se uvjetno pokreću aktuatori postavljanjem odgovarajućih izvoda GPIO za upravljanje relejima. Programski kod stvaranja brojača i funkcije povratnog poziva za vodenu pumpu prikazan je programskim odsječkom 5.1.

esp_err_t WATER_PUMP_init(void)

{

gpio_set_direction(WATER_PUMP_GPIO, GPIO_MODE_OUTPUT);

WATER_PUMP_timer = xTimerCreate("WATER_PUMP_update", (WATER_PUMP_ACTIVE_DURATION * 1000) / portTICK_PERIOD_MS,

pdFALSE, NULL, WATER_PUMP_update);

if (WATER_PUMP_timer)

return ESP_OK;

return ESP_FAIL;

}

static void HEATER_update(TimerHandle_t handle)

{

HEATER_BUSY = false;

gpio_set_level(HEATER_GPIO, 0);

esp_rmaker_param_update_and_report(

esp_rmaker_device_get_param_by_name(Heater, "Status"),

esp_rmaker_bool(HEATER_BUSY));

}

Kôd 5.1 – Funkcije stvaranja brojača (iznad) i povratnog poziva (ispod) vodene pumpe.

# 6. Platforma ESP RainMaker

ESP RainMaker platforma je koju nudi Espressif za IoT rješenja koja zahtijevaju praćenje i automatsko upravljanje uređajima na daljinu. Potpuno je prilagođena razvoju softvera na seriji čipova ESP32. Za te uređaje pruža potpuni alat za razvijanje softvera (SDK) i mobilnu aplikaciju, transparentni posrednički sloj u oblaku te alate za osobno računalo. Komunikacija uređaja s oblakom i razvoj aplikacije znatno su olakšani jednostavnim aplikacijskim programskim sučeljima integriranim u ESP-IDF [36].

Čvor je glavna logička jedinica ekosustava ESP RainMaker. On predstavlja individualni uređaj (sustav s mikrokontrolerom) koji se preko klijenta (mobilne aplikacije ili sučelja naredbenog retka) povezuje na oblak. Veza između čvora i oblaka postiže se sigurnim protokolom za razmjenu poruka u stvarnom vremenu MQTT (engl. Message Queuing Telemetry Transport). Veza se osigurava protokolom TLS (engl. Transport Layer Security), kojim se generiraju ključevi po certifikatu X.509 za pristupanje oblaku tijekom koraka primanja zahtjeva [38]. Princip komunikacije prikazan je slikom (Slika 6.1).

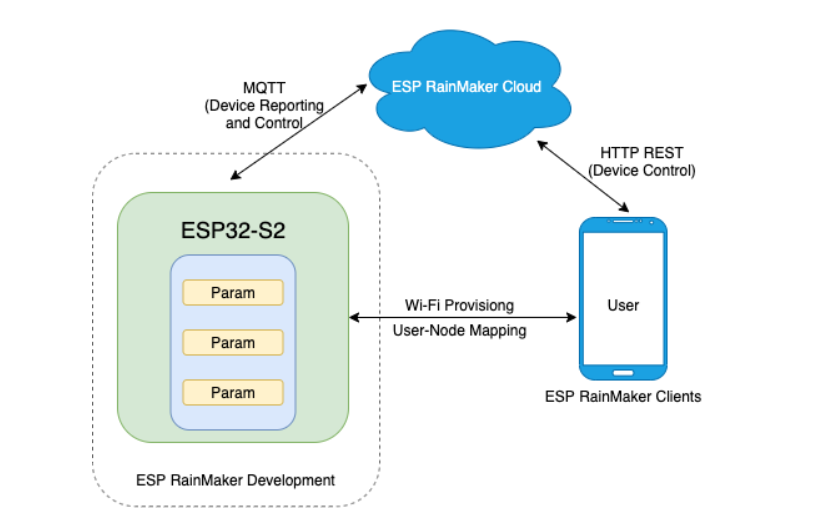
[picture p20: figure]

Slika 6.1 Princip komunikacije između čvora, klijenta i oblaka [41].

## 6.1. Povezivanje

Prvo je potrebno uspostaviti komunikaciju između čvora i klijenta, što se postiže u koraku postavljanja Wi-Fi mreže (engl. Wi-Fi provisioning). U tom koraku klijent šalje jedinstvenu korisničku oznaku i slučajno generirani tajni ključ čvoru (mikrokontroleru), a zauzvrat od njega dobiva identifikator čvora (engl. node Id). Oznaka se čvora zajedno s tajnim ključem šalje oblaku usluge RainMaker. S druge strane, mikrokontroler izravno komunicira s oblakom protokolom MQTT i šalje mu iste podatke (identifikator čvora, korisničku oznaku, tajni ključ). Klijent provjerava odgovor oblaka (engl. request Id); ako se podatci čvora i klijenta poklapaju, povezivanje je uspješno, u protivnom se nastavlja provjeravanje do isteka dozvoljenog vremena [39].

Izravna komunikacija između čvora i oblaka moguća je samo ako je veza potvrđena. Potvrđivanje veze (engl. claiming) moguće je na više načina:

- samopotvrđivanje; ako je tajni ključ tvornički postavljen u memoriju eFuse mikrokontrolera,
- potpomognuto potvrđivanje (zadano), u kojem klijent (mobilna aplikacija), povezan s čvorom BLE vezom, razmjenjuje podatke s oblakom i omogućuje vezu,
- potvrđivanje koje vodi domaćin (engl. host), pri čemu korisnik uspostavlja vezu posebnim zahtjevom nakon prijave na korisnički račun [40].

## 6.2. Programski kod

Cijela je programska podrška pokaznog modela u potpunosti podređena aplikacijskim programskim sučeljima agenta ESP RainMaker. Korisnički je kod uokviren aplikacijskim funkcijama, koje preko agenta uspostavljaju komunikaciju s klijentom. Takva je organizacija prikazana slikom (Slika 6.2).

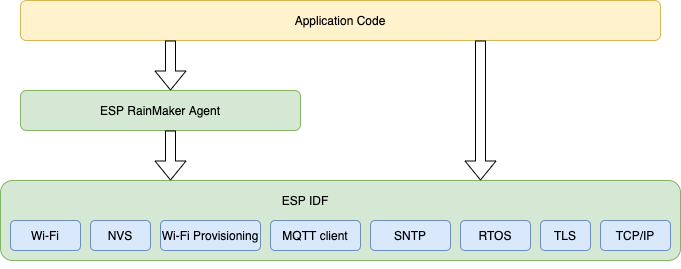
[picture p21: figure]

Slika 6.2 Proces softverskog razvoja preko agenta ESP RainMaker [37].

Struktura je projektnog direktorija sljedeća:

greenhouse/

├── .vscode/

├── build/

├── main/

│ ├── app_driver.c

│ ├── app_main.c

│ ├── app_priv.h

│ ├── CMakeLists.txt

│ ├── component.mk

│ ├── device.c

│ ├── device.h

│ ├── DHT11.c

│ ├── DHT11.h

│ ├── Kconfig.projbuild

│ ├── LTR-507.c

│ ├── LTR-507.h

│ ├── MQ-135.c

│ ├── MQ-135.h

│ ├── soil_moisture.c

│ ├── soil_moisture.h

├── managed_components/

├── CMakeLists.txt

├── dependencies.lock

├── Makefile

├── partitions_4mb_optimised.csv

├── partitions.csv

├── README.md

├── sdkconfig

├── sdkconfig.defaults

├── sdkconfig.defaults.esp32

├── sdkconfig.defaults.esp32c6

├── sdkconfig.defaults.esp32s2

└── sdkconfig.old

Kôd 6.1 – Struktura projektnog direktorija.

U datoteci app_main.c napisan je glavni program app_main(), koji se izvodi na mikrokontroleru. U njemu se prvo poziva funkcija app_driver_init() definirana u datoteci app_driver.c, u kojoj se nalazi korisnički program. Korisnički se program izvodi neovisno o funkcijama sučelja RainMaker. U njemu se inicijaliziraju senzori i aktuatori, početne se vrijednosti mjerenja i stanja aktuatora spremaju u globalne varijable te se pokreću brojači za senzorska očitavanja i rad aktuatora. Pri tome se koriste datoteke s imenima senzora, u kojima su implementirane funkcije iz prethodnih poglavlja. Period očitavanja, trajanje rada aktuatora i druge konstante definirane su u datoteci app_priv.h. Nakon pokretanja korisničkog programa slijede pozivi funkcija sučelja RainMaker.

Prvo se poziva funkcija app_wifi_init(), kojom se inicijalizira Wi-Fi mreža i postavke za Wi-Fi provisioning. Zatim se inicijalizira čvor pozivom funkcije esp_rmaker_node_init(), tako da mu se pridruži konfiguracija tipa esp_rmaker_config_t, ime i tip. Čvor sam po sebi ne posjeduje nikakvu vrijednost, pa mu je zato potrebno pridružiti uređaj tipa esp_rmaker_device_t.

Uređaj u pokaznom modelu predstavlja senzor ili aktuator, kojemu se pridružuju parametri vidljivi korisniku u mobilnoj aplikaciji. Uređaji su kreirani pozivima funkcija definiranih u datoteci device.c. Primjerice, uređaju DHT11 pridruženo je ime te parametri temperature i vlažnosti zraka. Ti se parametri periodički ažuriraju i dostavljaju oblaku pri svakom senzorskom čitanju pozivom funkcije esp_rmaker_param_update_and_report(). Jednostavnim postavljanjem zastavice PROP_FLAG_TIME_SERIES na uređaj omogućeno je iscrtavanje vrijednosti parametara pohranjenih u oblaku. Funkcija stvaranja uređaja prikazana je programskim odsječkom 6.2. Pri stvaranju uređaja korištene su već gotove komponente grafičkog sučelja definirane u biblioteci esp_rmaker_standard_params.h.

esp_rmaker_device_t *humiture_device_create(const char *dev_name,void *priv_data, int temperature, int humidity)

{

esp_rmaker_device_t *device = esp_rmaker_device_create(dev_name, ESP_RMAKER_DEVICE_TEMP_SENSOR, priv_data);

esp_rmaker_device_add_param(device, esp_rmaker_name_param_create(ESP_RMAKER_DEF_NAME_PARAM, dev_name));

esp_rmaker_device_add_param(device, esp_rmaker_param_create("Temperature", NULL, esp_rmaker_float((float)temperature), PROP_FLAG_READ | PROP_FLAG_TIME_SERIES));

esp_rmaker_device_add_param(device, esp_rmaker_param_create("Humidity", NULL, esp_rmaker_float((float)humidity), PROP_FLAG_READ | PROP_FLAG_TIME_SERIES));

esp_rmaker_device_assign_primary_param(device, esp_rmaker_device_get_param_by_name(device, "Temperature"));

return device;

}

Kôd 6.2 – Stvaranje uređaja za senzor DHT11 u datoteci device.c

Aktuatorskim uređajima u datoteci app_main.c također je pridružena funkcija povratnog poziva. Kad korisnik unese željenu temperaturu odnosno vlažnost tla ili uključi LED rasvjetu, promjena parametra ažurira se u mobilnoj aplikaciji te se pošalje na oblak. Oblak tada pošalje zahtjev za ulazak u funkciju povratnog poziva. U toj se funkciji prepoznaje uređaj za koji je poslan zahtjev te se unesena vrijednost postavlja za željeni aktuator. Dio koda prikazan je ispod odlomka.

//pridruživanje funkcije povratnog poziva

esp_rmaker_device_add_cb(Heater, actuator_write_cb, NULL);

//funkcija povratnog poziva

static esp_err_t actuator_write_cb(const esp_rmaker_device_t *device, const esp_rmaker_param_t *param,

const esp_rmaker_param_val_t val, void *priv_data, esp_rmaker_write_ctx_t *ctx)

{

//postavljanje temperature termostata

app_set_heater(val.val.i);

}

Kôd 6.3 – Funkcija povratnog poziva i njezino pridruživanje grijaču

Nakon pridruživanja uređaja čvoru, pokreće se agent sučelja RainMaker pozivom funkcije esp_rmaker_start(), koji će izvršiti korak potvrđivanja veze, uspostaviti komunikaciju protokolom MQTT, objaviti početne vrijednosti parametara uređaja ispod čvora i dr. Konačno, pozivom funkcije app_wifi_start() čvor će se povezati s mrežom i obaviti korak postavljanja Wi-Fi mreže ako ona nije postavljena.

U ostatku glavnog programa inicijalizira se NVS memorijska particija te se omogućuju postavke smanjene potrošnje opisane u prethodnim poglavljima.

# 7. Pokazni model sustava za praćenje i regulaciju uvjeta u stakleniku

## 7.1. Sklopovski dio sustava

Pokazni se model (Slika 7.1) sastoji od tri dijela:

- upravljačke jedinice,
- senzorskog čvora,
- povezanih aktuatora.

Svi su dijelovi pričvršćeni na staklenik manjih dimenzija namijenjen za uzgoj mladica i biljaka u unutarnjem ili vanjskom prostoru. U staklenik je postavljen i spremnik vode za navodnjavanje. Dijelovi modela prikazani su slikom (Slika 7.2).

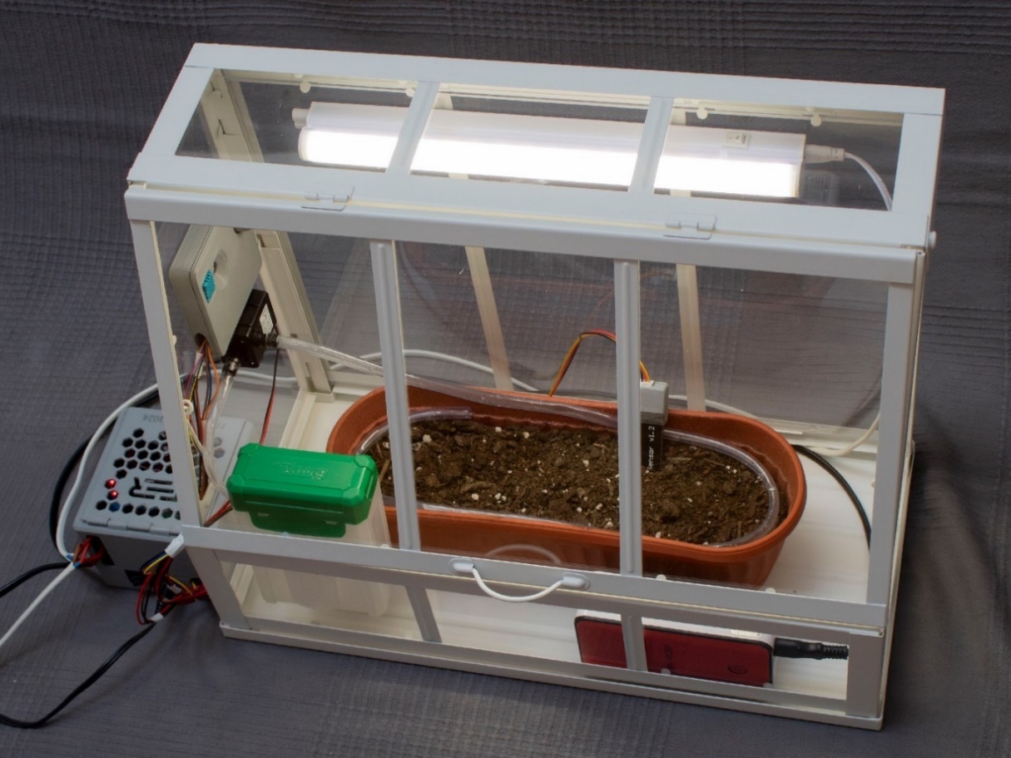
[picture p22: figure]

Slika 7.1 Pokazni model sustava za praćenje i regulaciju uvjeta u stakleniku.

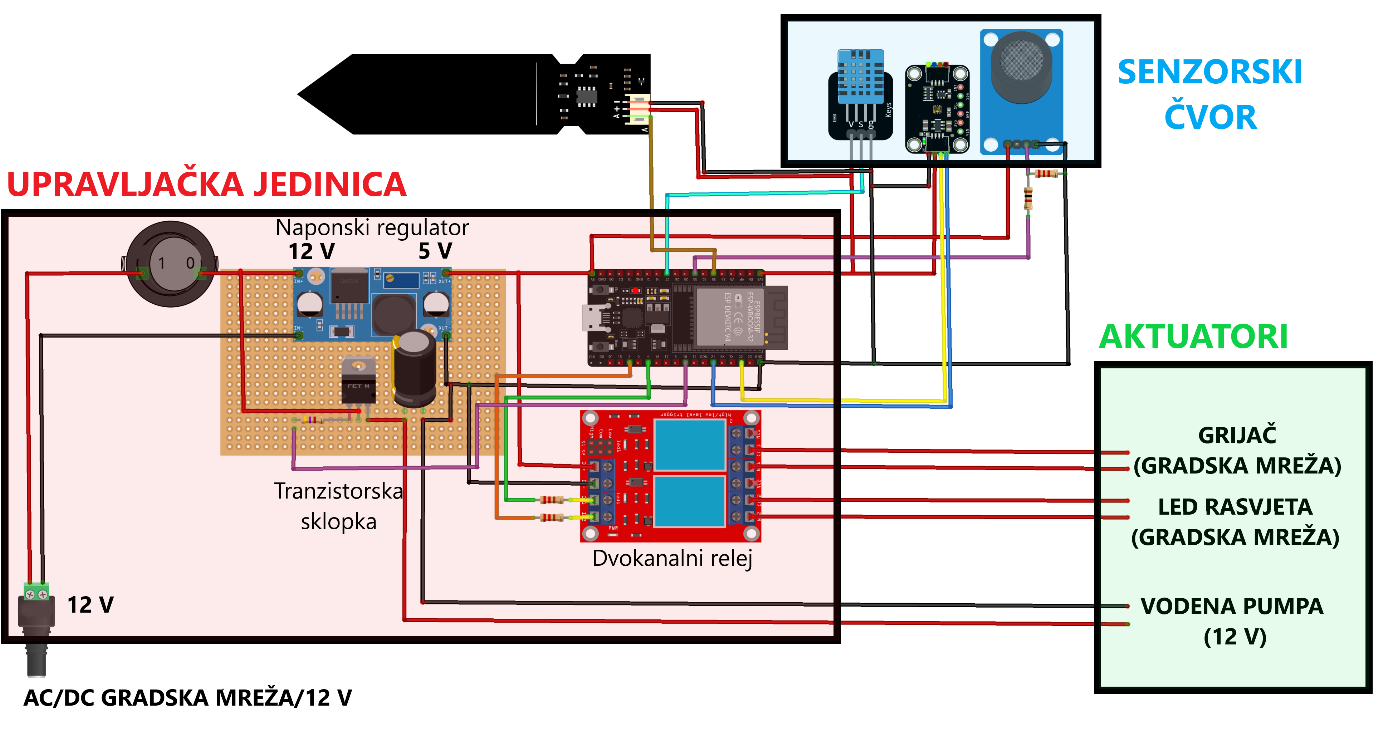
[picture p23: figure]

Slika 7.2 Pojednostavljena shema sustava izrađena u programu Fritzing.

Upravljačku jedinicu prikazanu slikom (Slika 7.3) čine mikrokontroler, pločica s napajanjem te pločica s dvokanalnim relejom. Cijeli se sustav napaja preko AC/DC 100-230 V/12 V mrežnog adaptera. Izlaznih se 12 V regulira na 5 V propusnim regulatorom s prekidanjem struje (engl. buck, foward, step-down) kako bi se 5 V dovelo na istoimeni izvod mikrokontrolera i na stezaljke za napajanje releja. Na pločici s mikrokontrolerom nalaze se konektori za jednostavno spajanje senzora i aktuatora. Relejnom se pločicom upravlja LED rasvjetom i grijačem, koji se napajaju iz gradske mreže. Vodena se pumpa napaja direktno s 12 V, a upravlja se jednostavnom tranzistorskom sklopkom na pločici s napajanjem. Ona se, kao i releji, preklapa signalom s GPIO izvoda mikrokontrolera. Na kućištu upravljačke jedinice nalazi se sklopka za uključivanje i isključivanje napajanja.

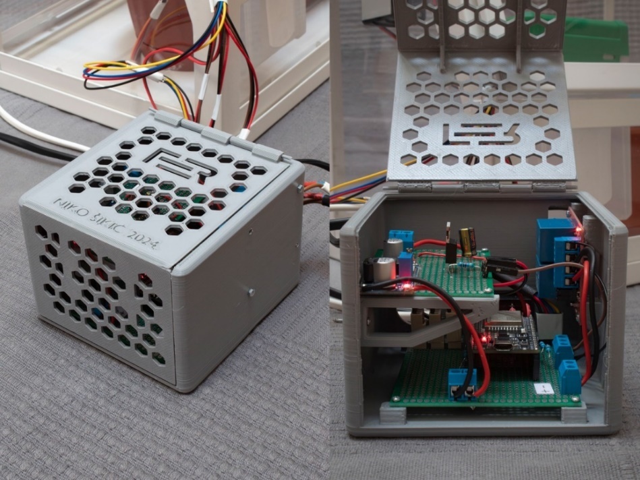
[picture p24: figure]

Slika 7.3 Upravljačka jedinica pokaznog modela s pločicama za napajanje, mikrokontroler i releje.

U senzorskom su čvoru postavljeni senzori DHT11, LTR-507-ALS-01 i MQ-135. Senzori su postavljeni u kućište, pri čemu je senzor MQ-135 nešto udaljen od ostalih senzora zbog zagrijavanja. Kapacitivni je senzor vlažnosti tla odvojen od čvora i zaštićen posebnim kućištem. Sva su kućišta dizajnirana u besplatnom programu Blender. Senzorski je čvor prikazan slikom (Slika 7.4).

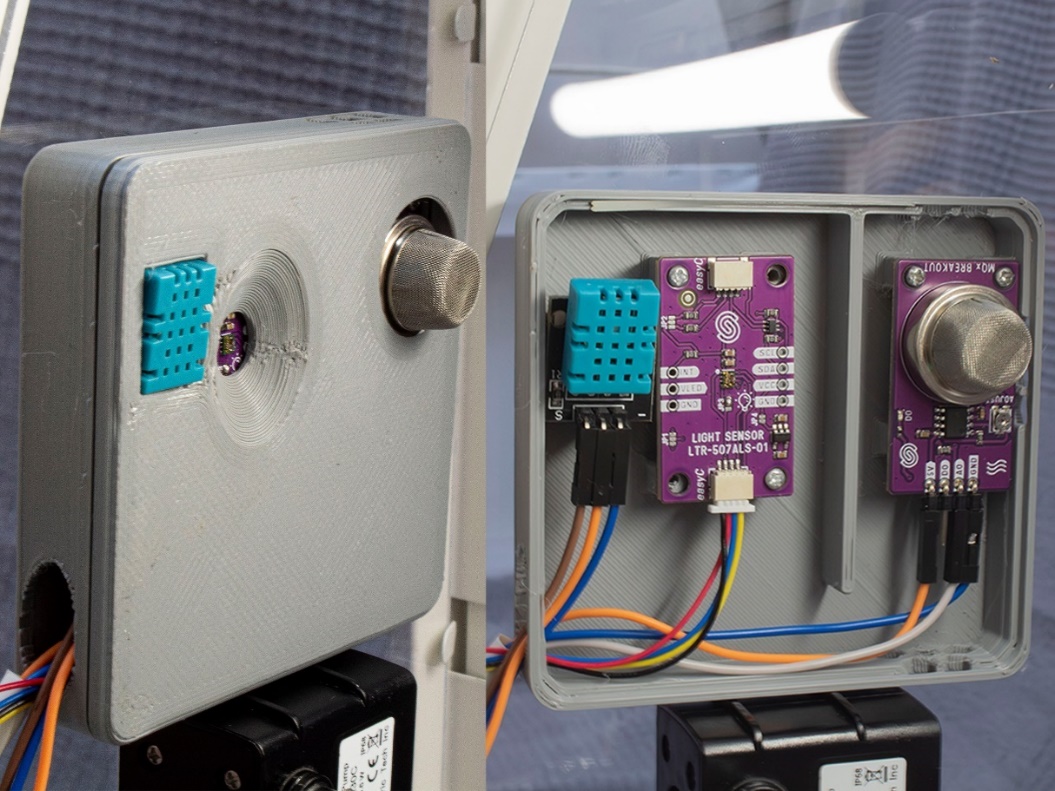
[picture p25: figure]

Slika 7.4 Senzorski čvor pokaznog modela sa senzorima DHT11, LTR-507-ALS i MQ-135.

## 7.2. Programska potpora

Programska podrška s uputama za korištenje dostupna je na poveznici https://github.com/Nixon275/Zavrsni_projekt .

Nakon programiranja mikrokontrolera potrebno je pokrenuti aplikaciju ESP RainMaker na mobilnom uređaju, prijaviti se na korisnički račun i započeti povezivanje. Mobilni uređaj u koraku postavljanja Wi-Fi mreže mora biti povezan na mrežu na koju se želi spojiti mikrokontroler. Bluetooth također mora biti uključen zbog potpomognutog potvrđivanja veze. Najjednostavniji način povezivanja jest skeniranjem QR koda ispisanog u terminalu nakon programiranja mikrokontrolera. Aplikacija će na temelju tog koda, koji je jedinstven za svaki mikrokontroler, proslijediti identifikator čvora oblaku i obaviti povezivanje. Nakon uspješnog povezivanja čvor s povezanim uređajima postaje vidljiv u aplikaciji i nadzornoj ploči platforme ESP RainMaker (engl. ESP RainMaker Dashboard). Postupak povezivanja i izgled čvora s uređajima u aplikaciji prikazani su slikom (Slika 7.5).

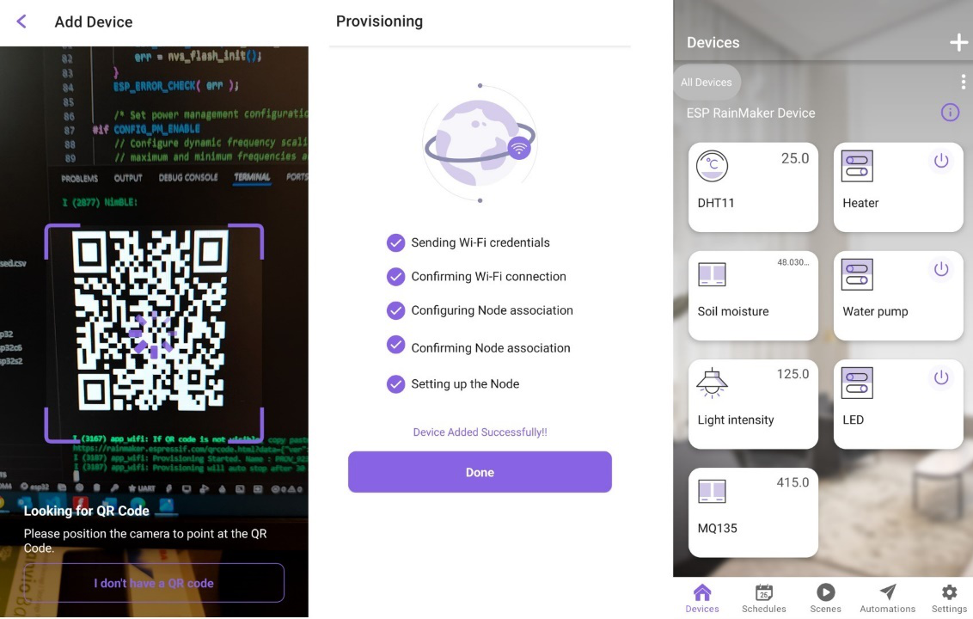
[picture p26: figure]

Slika 7.5 Postupak povezivanja sustava s mrežom i izgled početnog zaslona s uređajima spojenih na čvor u aplikaciji ESP RainMaker.

Na početnom su zaslonu vidljivi svi uređaji spojeni na čvor s istaknutim posljednjim mjernim rezultatom (ako je u pitanju senzor) ili postavljenim stanjem (ako je u pitanju aktuator). Pritiskom na pojedini uređaj otvara se detaljniji prikaz (Slika 7.6), u kojem je moguće iscrtati mjerne rezultate pritiskom na ikonu pored promatranog parametra. Na zaslonu s iscrtanim rezultatima moguće je podesiti vremenski interval praćenja, metodu iscrtavanja, prikaz srednje vrijednosti i dr.

Slika 7.6 Detaljniji prikaz uređaja za senzor DHT11 (lijevo) i za grijač (desno) u mobilnoj aplikaciji. Zadana temperatura na grijaču postavljena je na 30 °C.

U detaljnijem prikazu uređaja grijača i vodene pumpe moguće je podesiti temperaturu odnosno vlažnost tla pomicanjem klizača u definiranom rasponu i time omogućiti automatsku regulaciju. LED rasvjetom upravlja se ručno jednostavnom sklopkom. Također je moguće podesiti raspored uključivanja uređaja odabirom izbornika za raspored (engl. Schedules) na početnom zaslonu. Time se može omogućiti paljenje LED rasvjete u određeno doba dana, ovisno o vrsti uzgajane biljke. Na početnom su zaslonu prisutni i drugi izbornici, poput automatizacije (engl. Automations), u kojem se upravlja aktuatorskim uređajima ovisno o mjernim vrijednostima. Kako je automatizacija izvedena neovisno o aplikaciji, ta se opcija nije razmatrala.

## 7.3. Rezultati

Sustav je tijekom višesatnog rada pokazao dostatnu robusnost i nije se pretjerano zagrijavao. Senzori su dostavljali mjerne rezultate na oblak platforme ESP RainMaker uz minimalno pogrešaka pri slanju. Najveće vrijednosne oscilacije uočene su kod mjernih rezultata senzora koncentracije ugljikova dioksida u zraku MQ-135, a njihov je uzrok potrebno vrijeme za zagrijavanje senzora. Odziv svakog aktuatora bio je brz i pravovremen. Na slici (Slika 7.7) prikazani su mjerni rezultati koncentracije ugljikova dioksida u zraku i promjene intenziteta svjetlosti uslijed preklapanja sklopke uređaja LED rasvjete. Svi su podatci iscrtani u mobilnoj aplikaciji ESP RainMaker.

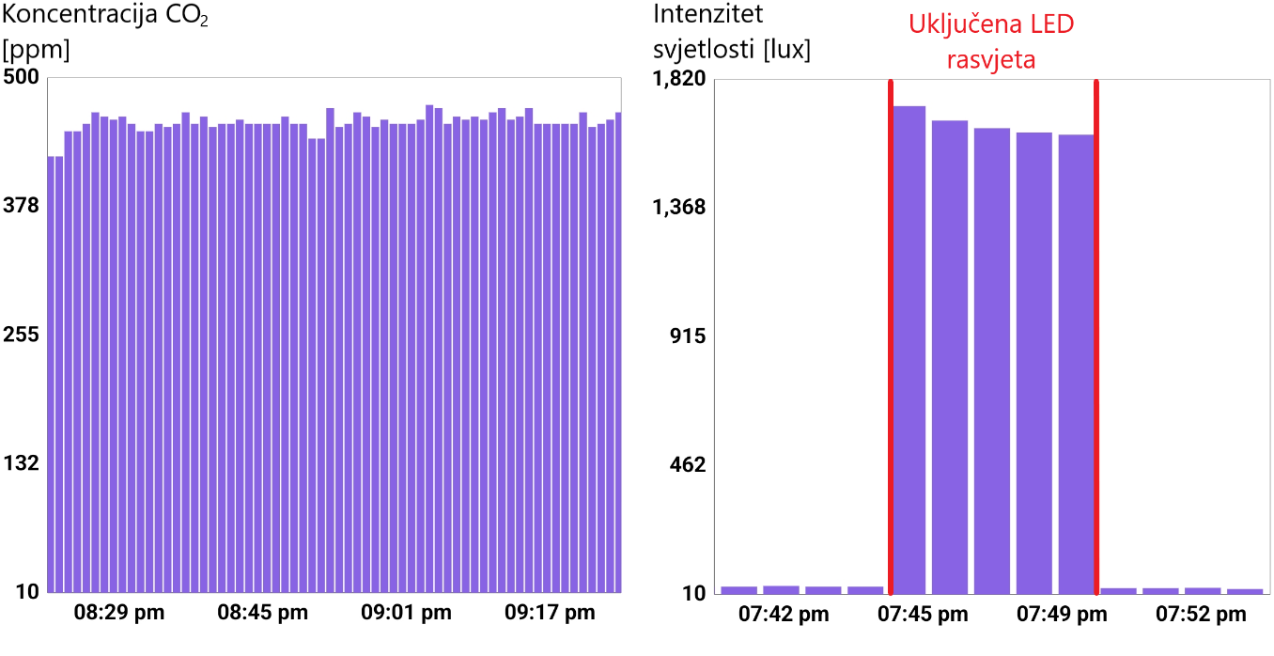
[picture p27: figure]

Slika 7.7 Iscrtani mjerni rezultati koncentracije ugljikova dioksida u zraku (lijevo) i intenziteta svjetlosti (desno) u mobilnoj aplikaciji ESP RainMaker.

Pri automatskoj regulaciji mikroklimatskih parametara trajanje rada aktuatora prilagođeno je njihovoj učinkovitosti i periodu očitavanja senzora. Slika 7.8 prikazuje automatsku regulaciju temperature zraka u stakleniku. Period očitavanja senzora postavljen je na 20 sekundi, a trajanje rada grijača 15 sekundi. Željena temperatura postavljena je na 30 °C, a vrijednosti su promatrane tijekom sat vremena. Grijač je nakon dostizanja postavljene vrijednosti temperaturu održavao s maksimalnom apsolutnom pogreškom od 1 °C. Zabilježeni su mjerni rezultati i za automatsku regulaciju vlažnosti tla tijekom sat vremena. Željena je vlažnost tla postavljena na 30%, period očitavanja na 10 sekundi, a trajanje rada vodene pumpe na 5 sekundi. U iscrtanim je rezultatima prikazanim slikom (Slika 7.9) apsolutno odstupanje od zadane vrijednosti manje od 5%. Navedeni su rezultati zadovoljavajući za demonstraciju automatske regulacije tipa uključi-isključi, a do detaljnijih bi se zaključaka došlo usporedbom rezultata s mjerenjima točnijeg mjernog instrumenta, što nije provedeno u radu.

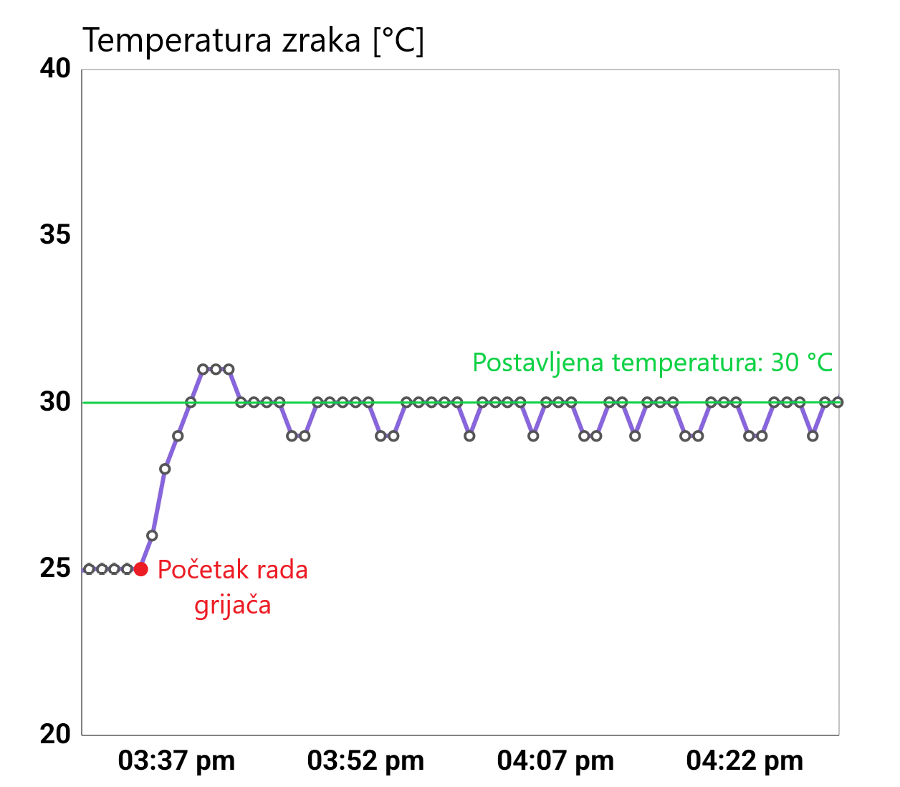
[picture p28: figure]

Slika 7.8 Iscrtani rezultati temperaturne regulacije grijačem u aplikaciji ESP RainMaker.

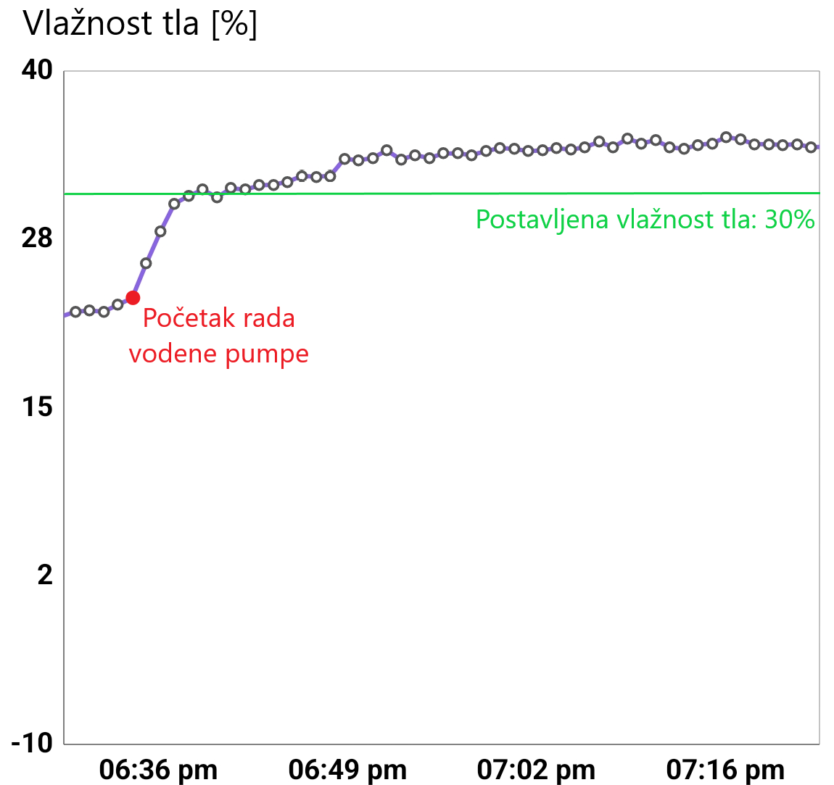
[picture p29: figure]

Slika 7.9 Iscrtani rezultati regulacije vlažnosti tla vodenom pumpom u aplikaciji ESP RainMaker.

# 8. Zaključak

Sustavi za praćenje i regulaciju mikroklimatskih uvjeta pri uzgoju biljaka u zatvorenom prostoru postaju sve razvijeniji. Moderni staklenički sustav tipično sadrži senzore i aktuatore za upravljanje mikroklimatskim parametrima poput temperature i vlažnosti zraka, koncentracije ugljikova dioksida u zraku, vlažnosti tla i intenziteta svjetlosti. U radu je demonstrirano da se navedeni parametri mogu upravljati i jeftinim komercijalno dostupnim senzorima i aktuatorima spojenim na mikrokontroler ESP32. Za komunikaciju s digitalnim senzorima razmatrani su i objašnjeni protokoli jednožične (1-wire) i dvožične (I2C) komunikacije, a istraženi su i provedeni postupci kalibracije analognih senzora. Aktuatori su regulirani regulatorom tipa uključi-isključi, a bolje bi se upravljanje postiglo primjenom PID regulatora. Praćenje i regulacija spomenutih parametara korištenjem odabranih senzora i aktuatora postignuto je izradom pokaznog modela.

Pokazni je model cjelokupno sklopovsko i programsko rješenje koje korisniku omogućuje prikaz i kontrolu nad mikroklimatskim parametrima u stakleniku manjih dimenzija. Razvoj programske podrške znatno je olakšan korištenjem platforme ESP RainMaker, kojom se olakšava bežična komunikacija i prikaz mjernih rezultata. U programskoj su podršci također implementirane postavke smanjene potrošnje, kojima se poboljšava autonomnost ugradbenog sustava.

Izradom i objavom ovakvih i sličnih rješenja naglašava se primjenjivost sve dostupnijih tehnologija u sklopu mreže povezanih uređaja interneta stvari. Takva rješenja postaju sve češća u modernom stakleničkom uzgoju, a njihov je razvoj važan za optimalan uzgoj biljaka u poljoprivredne ili istraživačke svrhe. Njima se olakšava proces proizvodnje i osigurava kvalitetniji proizvod, što je od izrazite važnosti u današnjem društvu, u kojem resursi postaju sve oskudniji, a potražnja za njima veća.

# Literatura

[1] M. A. Abas and M. Dahlui, Development of greenhouse autonomous control system for Home Agriculture project, 2015 International Conference on Advanced Mechatronics, Intelligent Manufacture, and Industrial Automation (ICAMIMIA), Surabaya, Indonesia (2015), str. 12-17
[2] Nemali, Krishna, History of Controlled Environment Horticulture: Greenhouses. HortScience 57.2 (2022), str. 239-246.
[3] Bhujel, A., Basak, J.K., Khan, F. et al. Sensor Systems for Greenhouse Microclimate Monitoring and Control: a Review. J. Biosyst. Eng. 45 (2020), str. 341–361
[4] Tunio, Mazhar & Gao, Jianmin. Technological Modernization and Its Influence on Agriculture Sustainability, Aeroponics Systems in Belt and Road Countries. (2021).
[5] Institut Kulinarstva New York. Hydroponic Garden. Poveznica: https://www.ice.edu/campuses/newyork/facilities-technology/hydroponic-garden; pristupljeno 20. lipnja 2024.
[6] Weiss Technik. Fitotron Modular Plant Growth Chambers Type HGC. Poveznica: https://www.weiss-technik.com/en/products/detail/fitotron-modular-plant-growth-chambers-type-hgc~p27622; pristupljeno 20. lipnja 2024.
[7] Bhujel, A., Basak, J.K., Khan, F. et al. Sensor Systems for Greenhouse Microclimate Monitoring and Control: a Review . J. Biosyst. Eng. 45, (2020.), str. 341–361.
[8] V. M. Quan, G. Sen Gupta and S. Mukhopadhyay, Review of sensors for greenhouse climate monitoring, 2011 IEEE Sensors Applications Symposium, San Antonio, TX, USA, (2011), str. 112-118.
[9] Espressif Systems. (2021). ESP32 Series Datasheet. Poveznica: https://www.espressif.com/sites/default/files/documentation/esp32_datasheet_en.pdf; pristupljeno 11. svibnja 2024.
[10] Espressif Systems. (2024). Getting Started with ESP-IDF. Poveznica: https://docs.espressif.com/projects/esp-idf/en/stable/esp32/get-started/index.html; pristupljeno 11. svibnja 2024.
[11] A. Maier, A. Sharp and Y. Vagapov, Comparative analysis and practical implementation of the ESP32 microcontroller module for the internet of things, 2017 Internet Technologies and Applications (ITA), Wrexham, UK, (2017.), str. 143-148.
[12] Espressif Systems. (2024). Getting Started with ESP32-DevKitC. Poveznica: https://docs.espressif.com/projects/esp-idf/en/stable/esp32/hw-reference/esp32/get-started-devkitc.html; pristupljeno 11. svibnja 2024.
[13] Espressif Systems. (2021). ESP32-WROOM-32E & ESP32-WROOM-32UE Datasheet. Poveznica: https://www.espressif.com/sites/default/files/documentation/esp32-wroom-32e_esp32-wroom-32ue_datasheet_en.pdf; pristupljeno 11. svibnja 2024.
[14] Espressif Systems. (2024). Wi-Fi Power Save Example. Poveznica: https://github.com/espressif/esp-idf/blob/master/examples/wifi/power_save/README.md; pristupljeno 11. Svibnja 2024.
[15] Components101. (2024). DHT11 Temperature Sensor. Poveznica: https://components101.com/sensors/dht11-temperature-sensor; pristupljeno 11. svibnja 2024.
[16] Aosong Electronics. (2020). DHT11 Technical Data Sheet. Poveznica: https://www.mouser.com/datasheet/2/758/DHT11-Technical-Data-Sheet-Translated-Version-1143054.pdf; pristupljeno 11. svibnja 2024.
[17] Espressif Systems. (2024). ADC API Reference. Poveznica: https://docs.espressif.com/projects/esp-idf/en/v4.4.8/esp32/api-reference/peripherals/adc.html; pristupljeno 20. travnja 2024.
[18] Espressif Systems. (2024). ESP32 Peripherals API Reference. Poveznica: https://docs.espressif.com/projects/esp-idf/en/stable/esp32/api-reference/peripherals/index.html; pristupljeno 20. travnja 2024.
[19] M. Saleh, I. H. Elhajj, D. Asmar, I. Bashour and S. Kidess, Experimental evaluation of low-cost resistive soil moisture sensors, IEEE International Multidisciplinary Conference on Engineering Technology (IMCET), Beirut, Lebanon, 2016, str. 179-184
[20] Hrisko, Joshua, Capacitive Soil Moisture Sensor Theory, Calibration, and Testing (2020).
[21] SunFounder, (2024). Ultimate Sensor Kit: Soil Moisture Sensor. Poveznica: https://docs.sunfounder.com/projects/ultimate-sensor-kit/en/latest/components_basic/10-component_soil.html; pristupljeno 27. Svibnja 2024.
[22] Hanwei Electronics. (2020). MQ-135 Gas Sensor Datasheet. Poveznica: https://www.electronicoscaldas.com/datasheet/MQ-135_Hanwei.pdf; pristupljeno 27. svibnja 2024.
[23] Vaisala. (2021). User Guide for CO2 Sensors. Poveznica: https://docs.vaisala.com/v/u/M210514EN-E/en-US; pristupljeno 27. svibnja 2024.
[24] CO2.Earth. (2024). Daily CO2 Levels. Poveznica: https://www.co2.earth/daily-co2; pristupljeno 27. svibnja 2024.
[25] Gironi, D. (2014). Cheap CO2 Meter Using MQ135 Sensor with AVR. Poveznica: https://davidegironi.blogspot.com/2014/01/cheap-co2-meter-using-mq135-sensor-with.html#.VJXAgsC3b; pristupljeno 27. svibnja 2024.
[26] K. B. Kumar Sai, S. R. Subbdareddy, A. K. Luhach, IOT based Air Quality Monitoring System Using MQ135 and MQ7 with Machine Learning Analysis, Scalable Computing: Practice and Experience 20, 4 (2019).
[27] Soldered Electronics. Air Quality Sensor MQ135 Breakout. Poveznica: https://soldered.com/product/air-quality-sensor-mq135-breakout/#gallery-2; pristupljeno 27. svibnja 2024.
[28] CiteSeerX. Document on Sensor Applications. Poveznica: https://citeseerx.ist.psu.edu/document?repid=rep1&type=pdf&doi=314537daa1f601f83044b25b68e2af6c8f331f3f; pristupljeno 27. svibnja 2024.
[29] Novitasari, I., Widiana, I. W. Design and Development of a Smart Home System with Real-Time Monitoring and Control, Makara Journal of Technology, 22,2 (2018), str. 89-96.
[30] Analog Devices. I²C Primer: What is I²C (Part 1). Poveznica: https://www.analog.com/en/resources/technical-articles/i2c-primer-what-is-i2c-part-1.html, pristupljeno 5. srpnja 2024.
[31] Lite-On. Datasheet for Lite-On Sensors. Poveznica: https://hr.mouser.com/datasheet/2/239/lite-on_lite-s-a0000286413-1-1749818.pdf; pristupljeno 27. svibnja 2024.
[32] Soldered Electronics. Digital Light Proximity Sensor LTR-507. Poveznica: https://soldered.com/product/digital-light-proximity-sensor-ltr-507-breakout/#gallery-2; pristupljeno 27. svibnja 2024.
[33] Sveučilište u Zagrebu. Predavanje na temu zatvorene petlje. Poveznica: https://www.fer.unizg.hr/_download/repository/RUS_predavanje_17.pdf; pristupljeno 24. svibnja 2024
[34] Control.com. On/Off Control Textbook. Poveznica: https://control.com/textbook/closed-loop-control/onoff-control/; pristupljeno 24. svibnja 2024.
[35] Parallax. PID Control Tutorial. Poveznica: https://learn.parallax.com/tutorials/language/pbasic/pid-control; pristupljeno 24. svibnja 2024.
[36] Espressif Systems. ESP-RainMaker Documentation. Poveznica: https://docs.espressif.com/projects/esp-rainmaker/en/latest/esp32/#; pristupljeno 27. lipnja 2024.
[37] Espressif Systems. ESP-RainMaker Firmware Development Guide. Poveznica: https://rainmaker.espressif.com/docs/firmware-dev.html; pristupljeno 27. lipnja 2024.
[38] Espressif Systems. ESP-RainMaker Node-Cloud Communication. Poveznica: https://rainmaker.espressif.com/docs/node-cloud-comm.html; pristupljeno 27. Lipnja 2024.
[39] Espressif Systems. ESP-RainMaker User-Node Mapping. Poveznica: https://rainmaker.espressif.com/docs/user-node-mapping.html; pristupljeno 27. lipnja 2024.
[40] Espressif Systems. ESP-RainMaker Claiming Devices. Poveznica: https://rainmaker.espressif.com/docs/claiming.html; pristupljeno 27. lipnja 2024
[41] Espressif Systems. Getting Started with ESP-RainMaker. Poveznica: https://rainmaker.espressif.com/docs/get-started.html; pristupljeno 27. lipnja 2024.

# Sažetak

Sustav za automatsko upravljanje mikroklimatskim uvjetima zatvorenog prostora za uzgoj biljaka

Kako bi se osigurao optimalan uzgoj biljaka u zatvorenom prostoru moderni staklenici implementiraju sustave za praćenje i automatsku regulaciju mikroklimatskih parametara. U radu su opisani najvažniji mikroklimatski parametri za uzgoj biljaka te najčešći senzori i aktuatori za njihovo upravljanje. Cilj rada bio je izrada pokaznog modela staklenika temeljenog na seriji mikrokontrolera ESP32 i razvojnom okviru ESP-IDF. Korištena je pločica ESP32-DevkitC V4 s integriranim funkcijama za Wi-Fi i BLE komunikaciju, uz modove rada smanjene potrošnje. Odabrani su senzori DHT11, kapacitivni senzor vlažnosti tla, MQ-135 i LTR-507-ALS-01. Za njihovu komunikaciju s mikrokontrolerom objašnjeni su protokoli 1-wire i I2C, a provedeni su i eksperimentalna mjerenja u postupku kalibracije analognih senzora. Razmatrane su metode automatske regulacije aktuatora, pri čemu je odabrana regulacija tipa uključi-isključi. Povezivanje sustava preko bežične mreže i pohrana podataka na oblak postignuti su korištenjem platforme ESP RainMaker. Pokazni model cjelovito je sklopovsko i programsko rješenje za automatsku regulaciju parametara u stvarnom vremenu. Takvim i sličnim IoT rješenjima povećava se produktivnost i smanjuje potreba za ljudskim radom u poljoprivrednoj proizvodnji.

Ključne riječi: staklenik, automatska regulacija, IoT, ESP32, ESP RainMaker, DHT11, MQ-135, senzor vlažnosti tla, LTR-507-ALS-01, 1-wire, I2C

# Summary

A system for automatic control of the microclimatic conditions in rooms for growing plants

To ensure optimal plant growth in enclosed spaces, modern greenhouses implement systems for monitoring and automatic regulation of microclimatic parameters. This project describes the most important microclimatic parameters for plant cultivation and the common sensors and actuators used for their management. The goal was to create a demonstration model of a greenhouse based on the ESP32 microcontroller series and the ESP-IDF development framework. Utilizing the ESP32-DevkitC V4 board, equipped with integrated Wi-Fi and BLE capabilities, the project incorporates power-saving features. The selected sensors include DHT11, a capacitive soil moisture sensor, MQ-135, and LTR-507-ALS-01. The 1-wire and I2C communication protocols with the microcontroller are explained, and experimental measurements were conducted during the calibration process of analog sensors. After evaluating various methods for automatic actuator control, on-off regulation was chosen. The system connects wirelessly to a network and stores data in the cloud via the ESP Rainmaker platform. The demonstration model is a comprehensive hardware and software solution for real-time automatic parameter regulation. Such IoT solutions increase productivity and reduce the need for human labor in agricultural production.

Keywords: greenhouse, automatic regulation, IoT, ESP32, ESP RainMaker, DHT11, MQ-135, soil moisture sensor, LTR-507-ALS-01, 1-wire, I2C

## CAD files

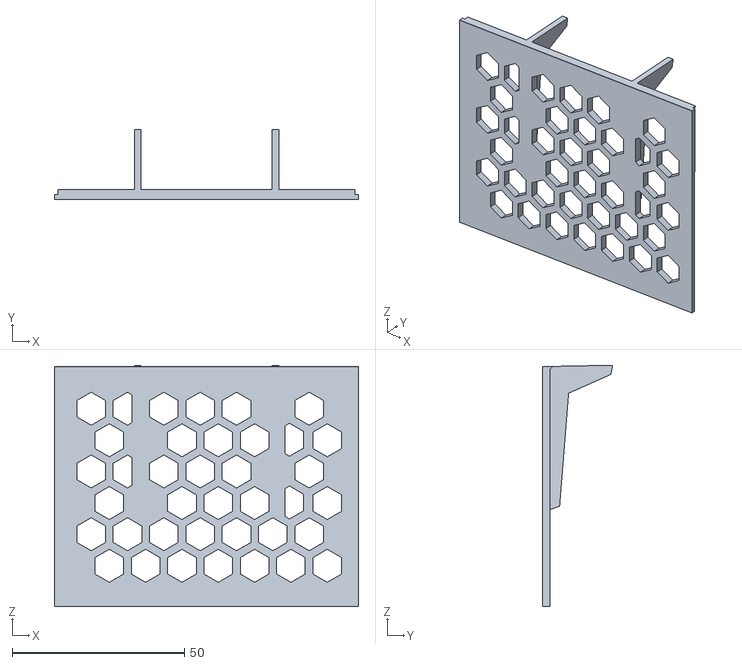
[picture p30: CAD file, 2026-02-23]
3D modeli/Control_Unit/CU_Lid_Front.stl
88.3 x 20.4 x 70.1

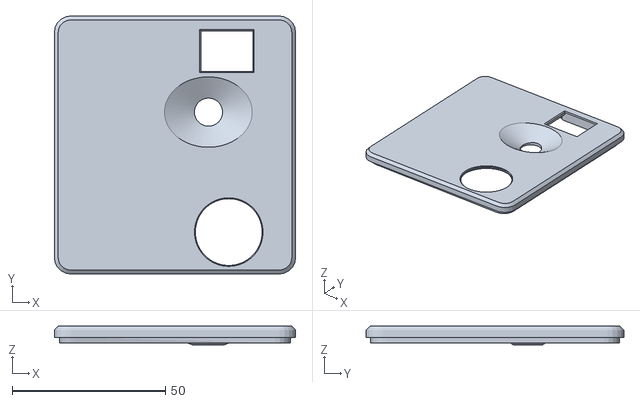
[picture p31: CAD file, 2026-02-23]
3D modeli/Sensor_Node/SN_Lid.stl
78.9 x 84.3 x 6.09

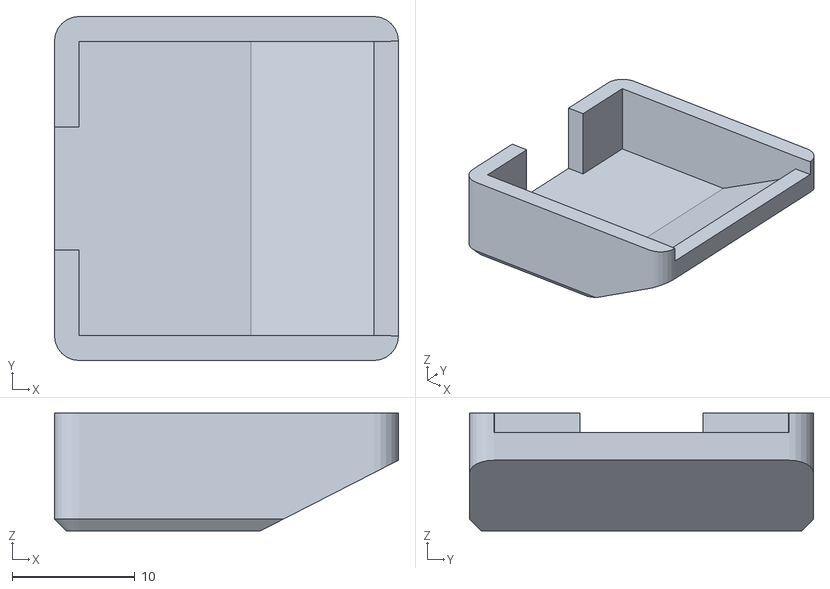
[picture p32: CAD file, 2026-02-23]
3D modeli/Sensor_Node/Soil_Moisture/SM_Top.stl
28.0 x 28.0 x 9.60

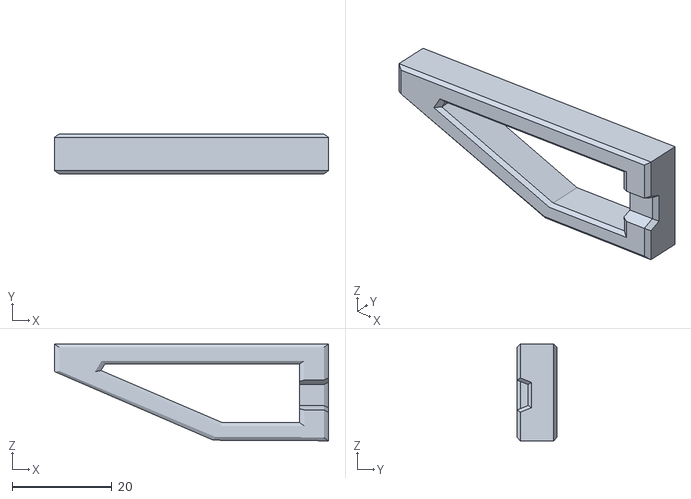
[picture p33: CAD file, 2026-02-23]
3D modeli/Control_Unit/CU_Shelf_Left.stl
54.8 x 8.00 x 19.3

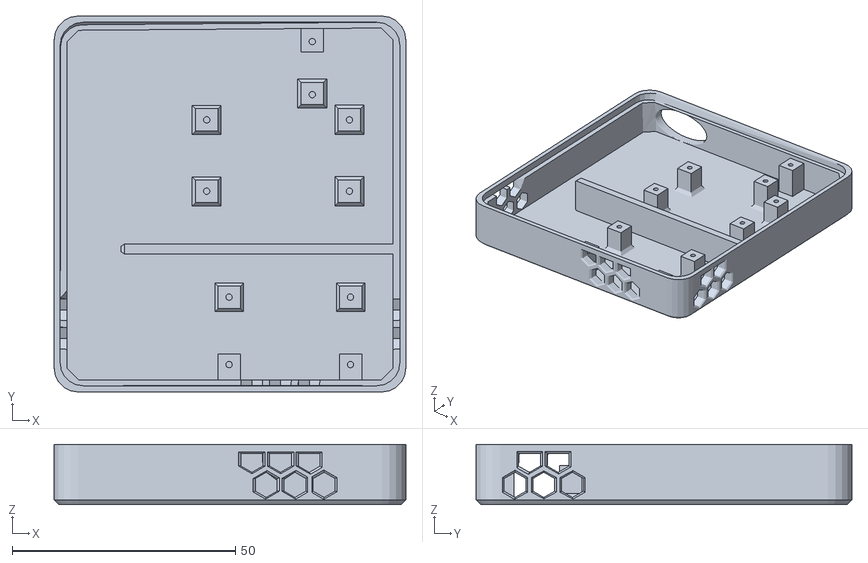
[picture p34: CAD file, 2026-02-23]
3D modeli/Sensor_Node/SN_Case.stl
78.9 x 84.3 x 13.5

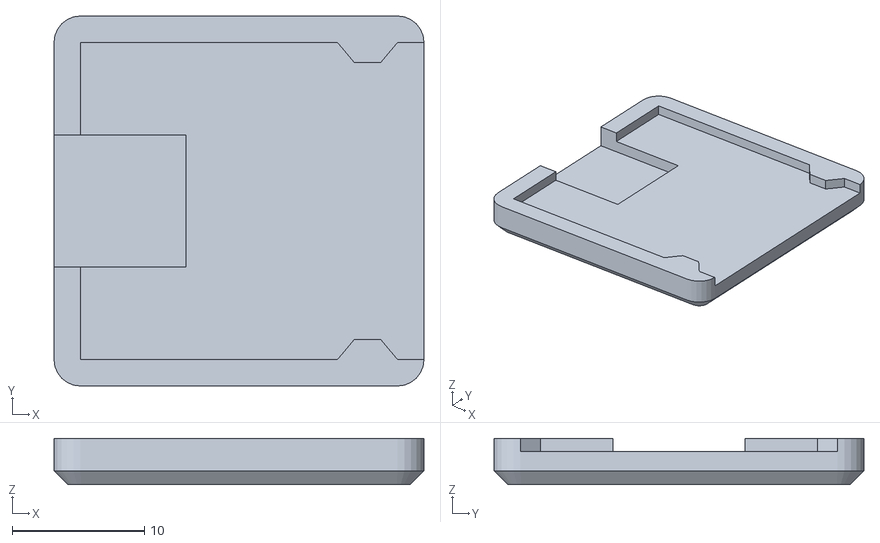
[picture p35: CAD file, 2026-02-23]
3D modeli/Sensor_Node/Soil_Moisture/SM_Bottom.stl
28.0 x 28.0 x 3.50

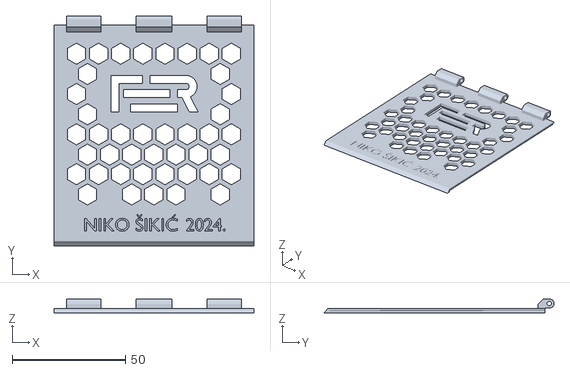
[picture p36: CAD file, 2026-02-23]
3D modeli/Control_Unit/CU_Lid_Top.stl
88.3 x 101.7 x 6.05

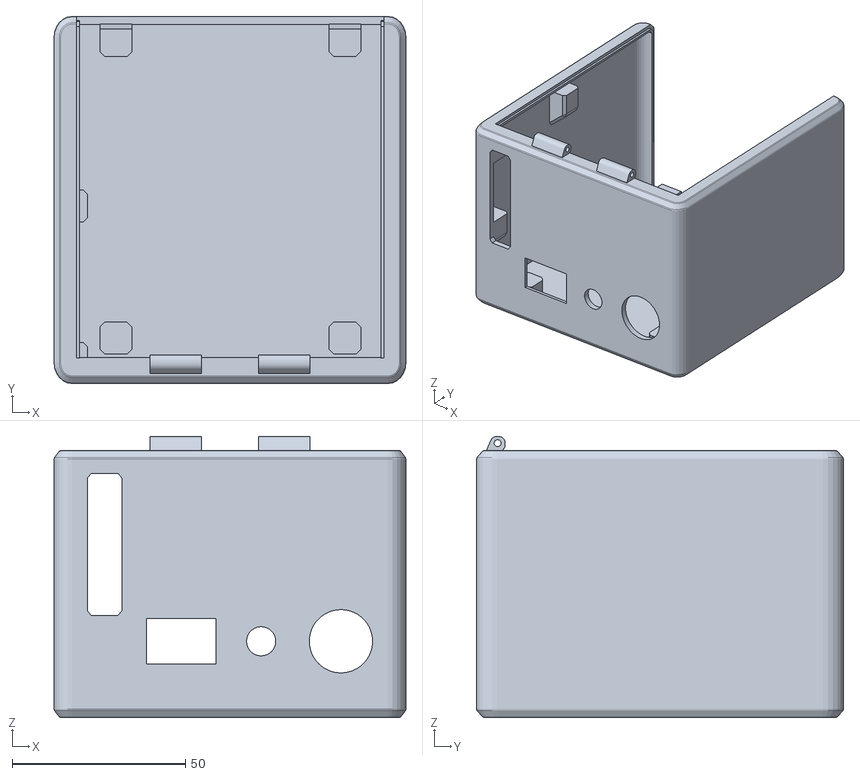
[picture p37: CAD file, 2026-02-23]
3D modeli/Control_Unit/CU_Case.stl
101.5 x 105.8 x 81.1

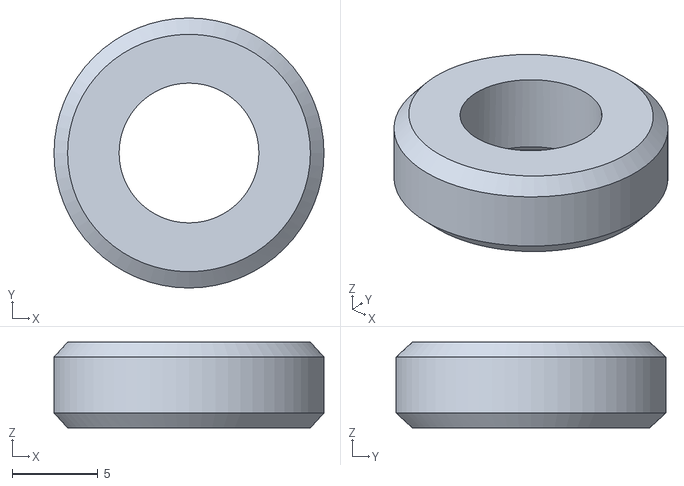
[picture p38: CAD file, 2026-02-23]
3D modeli/Control_Unit/CU_Nut.stl
15.7 x 15.7 x 5.00

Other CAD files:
3D modeli/Control_Unit/CU_Shelf_Right.stl

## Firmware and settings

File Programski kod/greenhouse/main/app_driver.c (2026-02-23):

#include <freertos/FreeRTOS.h>
#include <freertos/timers.h>
#include <sdkconfig.h>
#include <esp_rmaker_core.h>
#include <esp_rmaker_standard_types.h> 
#include <esp_rmaker_standard_params.h> 

#include <string.h>
#include <esp_log.h>

#include <app_reset.h>
#include <ws2812_led.h>
#include "app_priv.h"

#include "DHT11.h"
#include "soil_moisture.h"
#include "LTR-507.h"
#include "MQ-135.h"


static TimerHandle_t SENSOR_timer, HEATER_timer, WATER_PUMP_timer;

static bool HEATER_BUSY = false;
static bool WATER_PUMP_BUSY = false;
static int LED_STATE = 0;
static int HEATER_temp = HEATER_DEFAULT_TEMP;
static int WATER_PUMP_soil_moisture = WATER_PUMP_DEFAULT_SOIL_MOISTURE;

static int temperature, humidity, light_intensity, ppm;
static float soil_moisture;

static void SENSOR_app_update(TimerHandle_t handle)
{
    struct dht11_reading read = DHT11_read();
    temperature = read.temperature;
    humidity = read.humidity;

    esp_rmaker_param_update_and_report(
            esp_rmaker_device_get_param_by_name(DHT11, "Temperature"),
            esp_rmaker_float((float)temperature));

    esp_rmaker_param_update_and_report(
            esp_rmaker_device_get_param_by_name(DHT11, "Humidity"),
            esp_rmaker_float((float)humidity));

    if(!HEATER_BUSY && app_get_temperature()<HEATER_temp) 
    {   
        HEATER_BUSY = true;
        gpio_set_level(HEATER_GPIO, 1);
        xTimerStart(HEATER_timer, 0);

        esp_rmaker_param_update_and_report(
            esp_rmaker_device_get_param_by_name(Heater, "Status"),
            esp_rmaker_bool(HEATER_BUSY));
    }

    soil_moisture = read_soil_moisture();
    esp_rmaker_param_update_and_report(
            esp_rmaker_device_get_param_by_name(Soil_moisture, "Soil moisture"),
            esp_rmaker_float((float)soil_moisture));


    if(!WATER_PUMP_BUSY && app_get_soil_moisture()<WATER_PUMP_soil_moisture) 
    {   
        WATER_PUMP_BUSY = true;
        gpio_set_level(WATER_PUMP_GPIO, 1);
        xTimerStart(WATER_PUMP_timer, 0);

        esp_rmaker_param_update_and_report(
            esp_rmaker_device_get_param_by_name(Water_pump, "Status"),
            esp_rmaker_bool(WATER_PUMP_BUSY));
    }

    ppm = MQ135_read();
    esp_rmaker_param_update_and_report(
            esp_rmaker_device_get_param_by_name(MQ135, "CO2 ppm"),
            esp_rmaker_float((float)ppm));

    light_intensity = LTR507_getLightIntensity();
    esp_rmaker_param_update_and_report(
            esp_rmaker_device_get_param_by_name(ALS, "Lux"),
            esp_rmaker_float((float)light_intensity));

}

static void HEATER_update(TimerHandle_t handle)
{
    HEATER_BUSY = false;
    gpio_set_level(HEATER_GPIO, 0); 

    esp_rmaker_param_update_and_report(
            esp_rmaker_device_get_param_by_name(Heater, "Status"),
            esp_rmaker_bool(HEATER_BUSY));
}

static void WATER_PUMP_update(TimerHandle_t handle)
{
    WATER_PUMP_BUSY = false;
    gpio_set_level(WATER_PUMP_GPIO, 0); 

    esp_rmaker_param_update_and_report(
            esp_rmaker_device_get_param_by_name(Water_pump, "Status"),
            esp_rmaker_bool(WATER_PUMP_BUSY));
}


int app_get_temperature()
{
    return temperature;
}

int app_get_humidity()
{
    return humidity;
}

float app_get_soil_moisture()
{
    return soil_moisture;
}

bool app_get_heater_status()
{
    return HEATER_BUSY;
}

bool app_get_water_pump_status()
{
    return WATER_PUMP_BUSY;
}

int app_get_light_intensity()
{
    return light_intensity;
}

int app_get_ppm()
{
    return ppm;
}

bool app_get_led_state()
{
    return LED_STATE;
}

esp_err_t app_set_heater(int temp)
{
    HEATER_temp = temp;
    return ESP_OK;
}

esp_err_t app_set_water_pump(int soil_moisture)
{
    WATER_PUMP_soil_moisture = soil_moisture;
    return ESP_OK;
}

esp_err_t app_set_led(bool state)
{
    LED_STATE = state;
    if (LED_STATE)
    gpio_set_level(LED_GPIO, 1);
    else
    gpio_set_level(LED_GPIO, 0);

    esp_rmaker_param_update_and_report(
            esp_rmaker_device_get_param_by_name(LED, "Power"),
            esp_rmaker_bool(state));
    
    return ESP_OK;
}

esp_err_t SENSOR_init(void)
{   
    //DHT11 init
    DHT11_init(DHT11_GPIO);
    struct dht11_reading init_read = DHT11_read();
    temperature = init_read.temperature;
    humidity = init_read.humidity;
    ESP_ERROR_CHECK(init_read.status); //abort() if initial reading false

    //ADC init
    adc_oneshot_unit_handle_t adc1_handle;
    adc_oneshot_unit_init_cfg_t init_config1 = {
    .unit_id = ADC_UNIT_1,
    .ulp_mode = ADC_ULP_MODE_DISABLE,
};
    ESP_ERROR_CHECK(adc_oneshot_new_unit(&init_config1, &adc1_handle)); //abort() if ADC setup error

    //soil moisture init
    soil_moisture_init(adc1_handle, ADC_CHANNEL_7, ADC_BITWIDTH_12, ADC_ATTEN_DB_12);
    soil_moisture = read_soil_moisture(); 

    //MQ135 init
    MQ135_init(adc1_handle, ADC_CHANNEL_5, ADC_BITWIDTH_12, ADC_ATTEN_DB_12);
    ppm = MQ135_read();

    //ALS init
    LTR507_init();
    light_intensity = LTR507_getLightIntensity();


    SENSOR_timer = xTimerCreate("Sensor_app_update_tm", (SENSOR_REPORTING_PERIOD * 1000) / portTICK_PERIOD_MS,
                            pdTRUE, NULL, SENSOR_app_update);
    if (SENSOR_timer) {
        xTimerStart(SENSOR_timer, 0);
        return ESP_OK;
    }
    return ESP_FAIL;
}

esp_err_t HEATER_init(void)
{
    gpio_set_direction(HEATER_GPIO, GPIO_MODE_OUTPUT);

    HEATER_timer = xTimerCreate("HEATER_update", (HEATER_ACTIVE_DURATION * 1000) / portTICK_PERIOD_MS,
                            pdFALSE, NULL, HEATER_update);
    if (HEATER_timer)
        return ESP_OK;
    return ESP_FAIL;
}

esp_err_t WATER_PUMP_init(void)
{
    gpio_set_direction(WATER_PUMP_GPIO, GPIO_MODE_OUTPUT);

    WATER_PUMP_timer = xTimerCreate("WATER_PUMP_update", (WATER_PUMP_ACTIVE_DURATION * 1000) / portTICK_PERIOD_MS,
                            pdFALSE, NULL, WATER_PUMP_update);
    if (WATER_PUMP_timer)
        return ESP_OK;
    return ESP_FAIL;
}

esp_err_t LED_init(void)
{
    gpio_set_direction(LED_GPIO, GPIO_MODE_OUTPUT);
    return ESP_OK;
}

void app_driver_init()
{
    SENSOR_init();
    HEATER_init();
    WATER_PUMP_init();
    LED_init();
}

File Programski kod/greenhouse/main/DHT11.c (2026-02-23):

#include <stdio.h>
#include "DHT11.h"
#include "esp_timer.h"
#include "rom/ets_sys.h"
#include "freertos/FreeRTOS.h"
#include "freertos/task.h"
#include "driver/gpio.h"

static gpio_num_t GPIO_pin;
static struct dht11_reading output;

static portMUX_TYPE mux = portMUX_INITIALIZER_UNLOCKED;
#define PORT_ENTER_CRITICAL() portENTER_CRITICAL(&mux)
#define PORT_EXIT_CRITICAL() portEXIT_CRITICAL(&mux)

esp_err_t wait_for_response (int time_us, int level)
{   int us_counter=0;
    while (gpio_get_level(GPIO_pin) == level)
    {
        ets_delay_us(1);
        us_counter++;
    }
    if (us_counter > time_us)
    return output.status = ESP_ERR_TIMEOUT;
    else
    return ESP_OK;
}

void DHT11_init(gpio_num_t pin)
{   
    vTaskDelay(pdMS_TO_TICKS(1000)); //DHT11 je nestabilan prvu sekundu
    GPIO_pin = pin;
}


static int sent_bit()
{
    int us_counter = 0;
    while (gpio_get_level(GPIO_pin) == 1 && us_counter < 70)
    {
        us_counter++;
        ets_delay_us(1);
    }

    if (us_counter >= 70)
    {
        output.status = ESP_ERR_INVALID_RESPONSE;
        return -1; 
    }
    else
    if (us_counter > 28)
    return 1;
    else return 0;
}

struct dht11_reading DHT11_read()
{   
    PORT_ENTER_CRITICAL();

    output.status = ESP_OK; 
    //1 - MCU spušta pin, čeka 18ms i podiže
    gpio_set_direction(GPIO_pin, GPIO_MODE_OUTPUT);
    gpio_set_level(GPIO_pin, 0);
    ets_delay_us(18000);
    gpio_set_level(GPIO_pin, 1);

    //2 - MCU čeka da DHT11 spusti razinu (max 40 us)
    ets_delay_us(40);

    //DHT šalje odgovor - prvo 1 80 us, onda 0 80 us, a MCU sluša
    gpio_set_direction(GPIO_pin, GPIO_MODE_INPUT);
    wait_for_response(80, 0);
    wait_for_response(80, 1);

    uint8_t DHT11_data[5] = {0,0,0,0,0};
    //počinje prijenos 40 bitova, prije svakog bita 
    //čeka se signal 50 us
    int bit;
    for (int i = 0; i < 40; i++)
    {   
        wait_for_response(50, 0);
        bit = sent_bit();
        DHT11_data[i/8] = (DHT11_data[i/8] << 1) | bit;
    }
    PORT_EXIT_CRITICAL();

    //provjera kontrolne sume
    int data_sum = 0;
    for (int i = 0; i < 4; i++)
    {
       data_sum  += DHT11_data[i];
    }
    if (data_sum != DHT11_data[4])
    {
        output.status=ESP_ERR_INVALID_SIZE;
        //printf("Error: %d + %d + %d + %d != %d\n", DHT11_data[0], DHT11_data[1], DHT11_data[2], DHT11_data[3], DHT11_data[4]);
    }
   
    //spremanje podataka
    if (output.status==ESP_OK)
    {
        output.humidity = DHT11_data[0];
        output.temperature = DHT11_data[2];
    }
    else
    ESP_ERROR_CHECK_WITHOUT_ABORT(output.status);

    return output;
}
